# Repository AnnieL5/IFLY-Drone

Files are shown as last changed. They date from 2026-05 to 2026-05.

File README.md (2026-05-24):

## IFly, our Quadcopter Drone
Introducing IFly, our UAV (unmanned aerial vehicle) RC (remote control) quadcopter drone that can be controlled via a Logitech game controller. Along with basic flying capabilities, it consists of an ESP-32 camera that provides live video feed of the drone, which can be viewed on the user’s computer/phone. 

The drone can be used for personal enjoyment, exploration purposes or experimental projects. 

Our target audience is anyone interested in using a drone: drone enthusiasts, researchers who need an aerial device, elderly people who have limited movement, law enforcement who need to monitor dangerous areas, and delivery services. 

## How to use it?

#### mechanics
3D Cad files

#### docs
- BOM
- Journal
- Other documents

#### Firmware

DRONECODE - Code stored on the drone (in the Raspberry PI Pico)

OFFICIAL_ComputerArduino - Code in the Arduino UNO for receiving controller input and rf communication

OFFICIAL_XBox - Code ran on a computer with any python interpreter. Receives Xbox input and sends it to the Arduino via Serial communication

OFFICIAL_CameraWebServer - code for the ESP32-CAM module

## User Guide

### Safety: 
- Always fly in open space, away from people, wires, trees, and airports;
- Check for no fly zones in your region;
Do not fly in poor weather conditions such as raining, windy, or thunderstorms 
- Keep the drone within line of sight;
- Do not touch the propellers during operation/when spinning;
- Wear safety glasses for extra protection.

### Before Flight:
- Make sure the battery is sufficiently charged (between 14.8V to 16.8V);
- Place the drone on a flat ground, in an open space away from people;
- For safety reasons, tie the legs of the drone to some heavy objects to prevent accidents;
- Double check that the propellers are tight and there are no loose screws.

### Attaching the Battery:
- Carefully slide the battery into the space under the blue block/upper frame plate with the power cords facing the back of the drone (white arms);
- Strap the battery onto the drone with the provided velcro;
- Adjust the position of the battery so it aligns with the white line;
- Plug in the balance port to the battery checker, with the negative side plugged on the left side of the checker.

### Taking a Flight - Change Throttle:
- If the product is not pre-uploaded with the change throttle code;
- Download files in DRONECODE from https://github.com/AnnieL5/TEJ4M-Drone2024-25/tree/master 
- Open Thonny and connect to the Raspberry Pi Pico via a Micro-USB cable;
- Upload all downloaded files to Pico;
- Save the files;
- Open Arduino IDE on another computer, plug in the Arduino-RF Transmitter and open Serial Monitor;
  
    The following message should appear: 
    “Arduino TX Starting
    TX Ready…
    Please enter the message you wish to be communicated:”

- Plug in the battery to power the drone;
- The drone should beep 6 times; the gyro will then calibrate and the propellers will start rotating within 10 seconds;
- Send a number with two decimal places via the Serial Monitor to change the speed of the propellers (currently at 1.10, take-off at 1.35, landing at 1.00 and max 2.00).The motors will emergency stop once the drone has tilted more than 15 degrees in pitch or roll; power cycle to restart. 

### Taking a Flight - Controller Input:
- If the product is not pre-uploaded with the Controller Input code,

    Download files in DRONECODE from https://github.com/AnnieL5/TEJ4M-Drone2024-25/tree/ChangThrottle ;
    Open Thonny and connect to the Raspberry Pi Pico via a Micro-USB cable;
    Upload all downloaded files to Pico;
    Save the files.

- Open Arduino IDE on another computer, plug in the Arduino-RF Transmitter and the controller:

    The following message should appear: 
    “Arduino TX Starting
    TX Ready…
    Please enter the message you wish to be communicated:”
- Plug in the battery to power the drone
- The drone should beep 6 times and the gyro will calibrate;
- Press the specific button on the diagram to start the drone; it will take-off automatically
- Follow the diagram to control the drone. It will emergency stop once the drone has tilted more than 15 degrees in pitch or roll; power cycle to restart. There is also a safety time limit of 60 seconds once the drone takes off (throttle above 1.1).

### Camera - Acess the code in the CameraWebServer branch
**First time use:**

    Open Arduino IDE;
    Plug in the camera to the computer using a USB-MicroUSB cable;
    Download and open the files in the OFFICIAL_CameraWebServer from Github;
    Change the WIFI credentials to your own WIFI name and password;
    Upload the code;
    Open Serial Monitor and wait for it to provide a link to a website;
    Open the link in any browser.

**Other times:**
- Power the camera using 5V and connect to GND;
- Open WIFI/Hostpost that is recorded in the program stored inside the module;
- Wait until the camera is connected;
- Open the same website as the first time use and enjoy.

### Battery Maintenance:
- Do not puncture, wet, or throw the battery;
- Replace the battery if it puffs, has unusual smell, or smokes;
- Do not go below 3.7V per cell (can be seen from the battery checker);
- Always use a quality Lipo battery charger when charging or discharging;

**Charging**
- Never leave the battery charging unattended;
- Always balance charge the battery at a 1C rate (3.3A) to a max of 16.8V (or 4.2V per cell);
- Do not overcharge the battery.

**Discharging**
- Never discharge the battery unattended;
- Discharge battery back to storage level (3.85V per cell) if you are not going to use the drone again for a long period of time (3 days or more);
- Discharge at a rate of 1C or less (or whatever rate the charger deems appropriate);
- Never completely discharge the battery, unless it is to be disposed;
- Store the battery on a non-flammable surface and away from flammable objects; do not keep the battery plugged in if you are not using the drone.

## Thanks for checking it out!
Made by Jennifer Liu and Tianyi(Annie) Liang. 

If there are any questions or if you would like to contribute, please reach out to atianyi.liang@gmail.com. Your support is greatly appreciated!

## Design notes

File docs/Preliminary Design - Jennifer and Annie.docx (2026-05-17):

Preliminary Design Document

for “Drone”

Version 1.0

Jennifer and Annie

Oct 27, 2024

# Table of Contents

Table of Contents 2

1. Introduction 3

1.1 Project Overview 3

2. Product Design 4

2.1 Block Diagram 4

2.2 Sub-Circuit Descriptions 4

2.2.1 Sub-Circuit #1: ESCs (Electronic Speed Controllers) 4

2.2.2 Sub-Circuit #2: ESCs, Motors, and Propellers 5

Battery 6

2.2.3 Sub-Circuit #3: Raspberry Pi Pico and Active Buzzer 6

2.2.4 Sub-Circuit #4: Raspberry Pi Pico and MPU-6050 7

2.2.5 Sub-Circuit #5: RF transceivers 7

2.2.6 Sub-Circuit #6: Raspberry Pi Pico, RF transceiver, and SPI 8

SPI Communication 9

2.2.7 Sub-Circuit #7: Arduino Leonardo and RF Transceiver 9

2.2.8 Sub-Circuit #8: ESP32 CAM-MB 10

2.3. Product Interfaces 10

2.3.1 Internal Interfaces 10

2.3.1.1 Raspberry Pi Pico and ESCs 10

2.3.1.2 ESCs and Motors 11

2.3.1.3 4s Lipo Battery and ESCs 11

2.3.1.4 4s Lipo Battery and Power Switch 12

2.3.1.5 Raspberry Pi Pico and MPU-6050 12

2.3.1.6 Raspberry Pi Pico and NRF24L01 Transceiver 12

2.3.1.7 Raspberry Pi Pico and ESP 32-CAM-MB 12

2.3.2 External Interfaces 13

2.3.2.1 Arduino Leonardo and NRF24L01 Transceiver 13

2.3.2.2 Xbox Controller and Arduino Leonardo 13

2.3.2.3 Communication between NRF24L01 Transceivers 13

2.3.2.4 ESP 32-CAM and Computer 13

2.3.2.5 Battery pack and Arduino Leonardo 14

3. Scheduling 14

3.1 Tasks 14

Task #1: Drone 14

Task #2: Camera 14

3.2 Gantt Chart Schedule 15

APPENDIX 16

Appendix A. Schematic 16

Appendix B. Parts List 16

Appendix C. References 19

# 1. Introduction

## 1.1 Project Overview

The Drone - as indicated by its name - is an UAV (unmanned aerial vehicle) VTOL (vertical Take-Off and landing) quadcopter drone, perfect for anyone interested in aerospace or aviation, enthusiasts looking for a fun new hobby, or researchers who might need an aerial device for experiments! The drone can be controlled through an XBox controller and is equipped with a camera, where live video data can be accessed from any computer. The drone also has a self-powered buzzer, great for easy identification of the drone amidst crashes or accidents. The drone flies in acro mode, intended for stable and non-rigours flying (i.e not for racing). Our made-up client is a Canadian drone manufacturer that wants us to design and build a prototype for a new quadcopter drone model. The end users will be the customers who are looking to purchase a drone. However, the drone is actually a project for the Grade 12 Computer Engineering course, TEJ4M, where the goal is to learn more about various engineering concepts while covering off the majority of the curriculum’s expectations. For a summary of the requirements of this project, please see the Hardware Requirements Specification (HRS) document for the Drone.

# 2. Product Design

## 2.1 Block Diagram

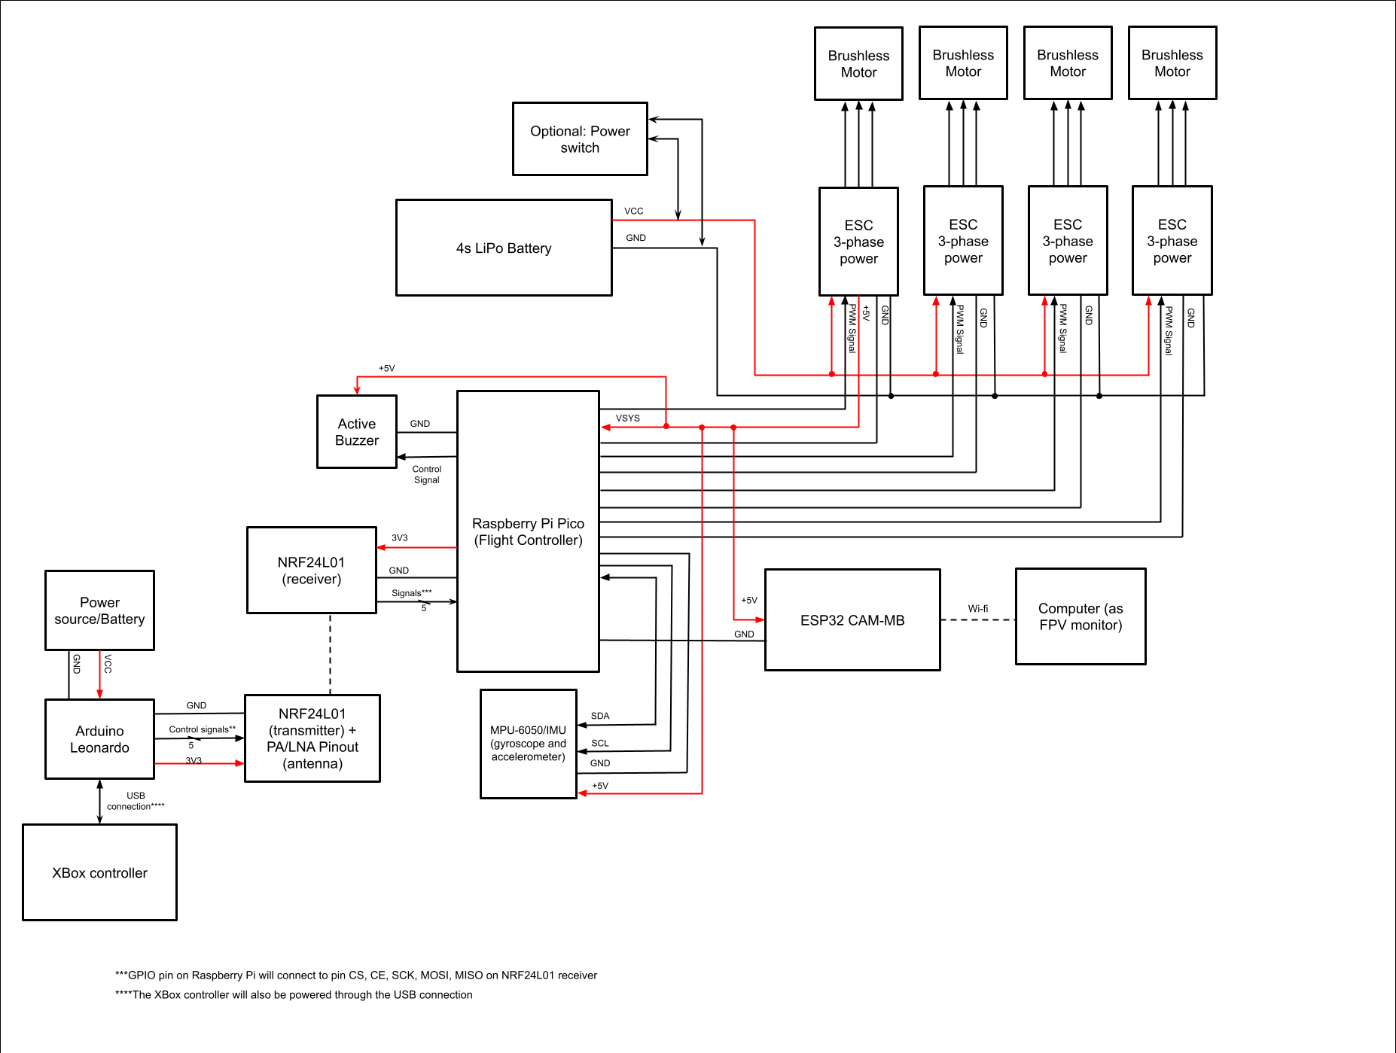
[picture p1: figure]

## 2.2 Sub-Circuit Descriptions

### 2.2.1 Sub-Circuit #1: ESCs (Electronic Speed Controllers)

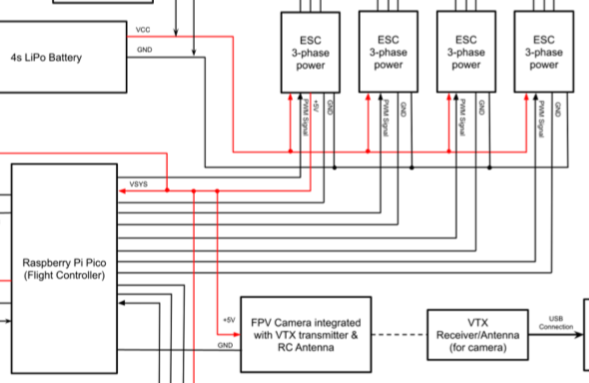
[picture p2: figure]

4 brushless ESCs will be used to control the throttle of each motor. The Raspberry Pi Pico has limited current (maximum output current of 12mA) and voltage output on its GPIO pin. In addition, it cannot generate the precise three-phase control needed to drive the motors. Therefore, an ESC will be used to control the speed of each motor.

The flight controller (Raspberry Pi Pico) uses PID controllers to determine the necessary adjustments to the speed of each motor to achieve the desired orientation (pitch, roll, yaw) of the drone. This process involves calculating the error between the desired angular rates (from the pilot's input via the Xbox controller) and the actual angular rates measured by the MPU-6050 for each axis. The PID controller computes correction values using proportional, integral, and derivative terms, each scaled by their respective gain values. The sum of these terms provides the control signal for each axis, which is then used to adjust the speeds of individual motors accordingly. Throttle (overall thrust) is managed separately to control altitude, with the PID adjustments superimposed to maintain or change orientation.

The flight controller, utilizing a Raspberry Pi Pico, communicates with each Electronic Speed Controller (ESC) through Pulse Width Modulation (PWM) signals. The duty cycle of the PWM signal dictates the throttle level: a higher duty cycle results in faster motor rotation. Specifically, the PWM signal operates at a frequency of 50 Hz, where a pulse width of 1 ms corresponds to zero throttle and a pulse width of 2 ms signifies full throttle. Throttle adjustments are made incrementally between these two pulse widths.

Each ESC contains a microcontroller connected to six MOSFET transistors—two MOSFETs per motor wire. These MOSFETs function as switches, regulating the current to the motor's three-phase coils. At higher throttle levels, the MOSFETs switch more rapidly, increasing the motor's speed. Between the ESC microcontroller and the MOSFETs lies a gate driver, which amplifies the low-voltage PWM signals from the microcontroller to the high-voltage required by the MOSFETs.

The PWM signals for each ESC (U4-3, U5-3, U6-3, U7-3) are connected to corresponding GPIO pins on the Raspberry Pi Pico (U1-4, U1-34, U1-20, U1-21).

Each ESCs is powered through the 4S Lipo battery and connected to both the battery’s ground and GND pins (U1-3, U1-18, U1-33, U1-23) on the Raspberry Pi Pico. The power and ground wires for the ESC will be soldered directly to the PCB board of the frame.

Unlike a linear BEC, a switching BEC uses a small FET transistor to rapidly switch the battery voltage on and off. This switched voltage is then filtered through an inductor and capacitor to smooth out the ripple, producing a steady DC voltage. This method avoids overheating and reduces power wastage.To avoid buying another separate on-board voltage regulator, the Raspberry Pi Pico will be powered through the VSYS pin (U1-39) by one of the ESCs (U4-4).

### 2.2.2 Sub-Circuit #2: ESCs, Motors, and Propellers

4 SunnySky 2212 980kv brushless motors will be used, each with a 9450 2-blade propeller.

Compared to brushed motors, brushless motors have minimal friction and are more efficient. 2212 motors are a common and popular motor size for the F450 frame, measuring 22mm in stator diameter and 12mm in stator height - these dimensions allow for a balance in motor responsiveness and cooling.

Loaded with all the parts, the drone weighs a total of ~1155g. To achieve a thrust-to-weight ratio of at least 2:1, each motor needs to be able to produce at least 578g of thrust. With a larger frame such as the F450, larger propellers are more suitable as they can move more air and thus generate more thrust. They also provide better flight stability. To generate the greater amount of torque needed to achieve the thrust required for the larger propellers, a lower motor Kv rating is required. This is due to the inverse relationship between torque constant (amount of torque produced per amp of current to the motor) and Kv: K_t (Torque constant) = 1/(K_v) . Since T(torque)=K_t * Current , a higher torque constant generates more torque, which in turns generates more thrust. Accordingly, based on the thrust table below for the 2212 980v motor, the motor can produce over 578g of thrust with a 4S lipo (14.8V) and 9450 propellers while maintaining fair efficiency.

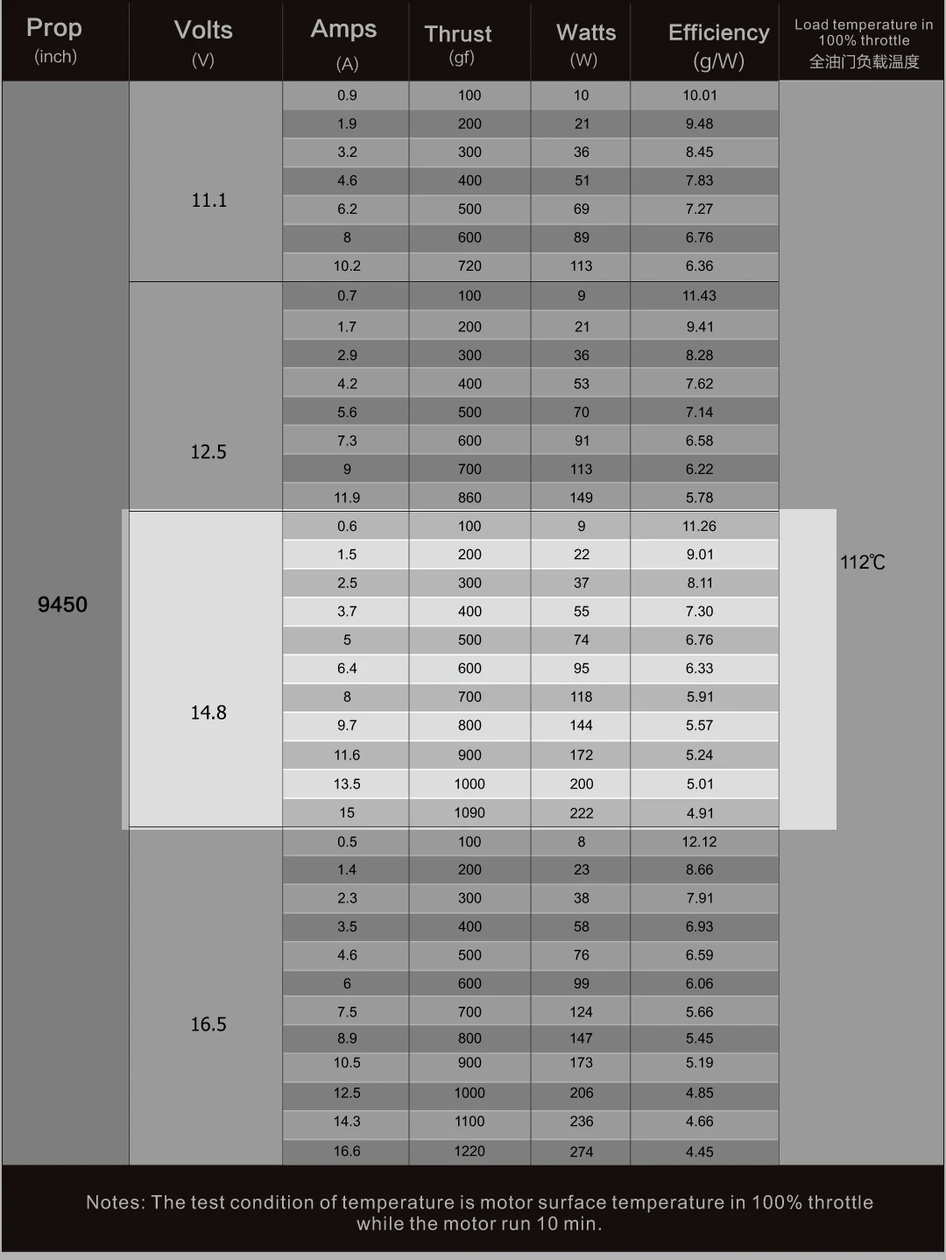
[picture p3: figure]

Each motor will be powered through three phase power from the ESCs. The motor is rated to have maximum continuous current of 20A/30S. Our ESCs are rated for a continuous current output of 30A, well above a 20% increase of the motor’s max current draw, ensuring that the ESCs won’t overheat.

Calculations from ecalc (https://ecalc.ch/xcoptercalc.php) based on components configurations for the drone:

*The results show that the electric power required is over the maximum power rating for the motor. However, this is most likely due to incorrect data from ecalc. Ecalc rates the maximum power limit for SunnySky 2212 980kv motors to be 115W, while SunnySky states that the motor has a maximum continuous power of 330W. Therefore, the motor should be able to generate enough power, and ecalc results are incorrect.

### Battery

The drone will be powered by a 4S 3300mAh Lipo Battery, with a minimum discharge rate of 60C and a nominal voltage of 14.8V. This provides ample current and voltage to the ESCs and motors.

Max Current = Battery Capacity & C rating

Max Current = 3.3 Ah * 60

Max Current = 198A

Each motor has a maximum current draw of 20A: Max current draw = 20*4 = 80A

Therefore the battery can safely handle the motor’s current draw. Each ESC is rated for a voltage input of 6.4v - 16.8v.

### 2.2.3 Sub-Circuit #3: Raspberry Pi Pico and Active Buzzer

The active buzzer with built-in 80mAh Lipo battery will be used for easy identification of the drone amidst crashes or accidents.

If the battery disconnects, the buzzer will sound in low volume for 40 seconds. After 40 seconds, the buzzer will sound at max volume of up to 110db for 40 seconds. The buzzer will flash a blue light in low light settings.

To manually activate the buzzer (if the battery isn’t disconnected):

The buzzer activates when current flows from BUZ+ to BUZ-. The buzzer has 3 connections with the Raspberry Pi Pico: BUZ+, GND, and BUZ-. BUZ+ (BZ1-1) is connected to VSYS (U1-39) on the Raspberry Pi Pico. GND (BZ1-3) is connected to GND (U1-28) on the Pico. BUZ- acts as the negative terminal for the buzzer’s internal circuits. When BUZ- is connected to GND, the circuit is complete and current flows through the buzzer, thereby activating it. Due to the limited current that GPIO pins can handle, a 2N7000 MOSFET will be used as a switch between BUZ- & GND. The transistor will be connected to a GPIO 22 (U1-29) on the Pico through a 1 kΩ resistor (to protect the pin from current spikes during switching).

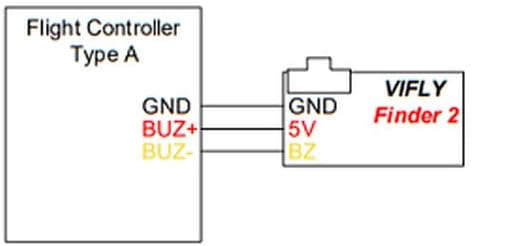
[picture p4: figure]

BUZ- will be connected to the drain of the transistor, and the source will be connected to a GND (U1-28) on the Pico. Since the transistor is used as a switch, it will operate only between the cutoff and saturation regions, not the linear (active) region.

GPIO 22 (U1-29) controls the gate voltage, which controls the drain-source channel, but is electrically isolated from the high-current path of the buzzer; the gate draws an extremely small current, protecting the GPIO pin from excessive load. The transistor has a continuous drain current of 200mA, which should be sufficient to handle the buzzer’s current.

When GPIO 22 is set HIGH (3.3V), the N-MOSFET turns on, the gate-source voltage (V_GS) exceeds the threshold voltage required to turn on the MOSFET. The MOSFET enters the enhancement mode and conducts between drain and source. This connects BUZ- to GND, and the buzzer activates.

### 2.2.4 Sub-Circuit #4: Raspberry Pi Pico and MPU-6050

A MPU-6050 will be used to measure the actual orientation along the three axes (pitch, roll, and yaw) at any time by measuring the drone’s angular velocity and linear acceleration. The MPU-6050 is a six-axis Inertial Measurement Unit (IMU) that combines a three-axis gyroscope and a three-axis accelerometer.

The MPU-6050 communicates with the Raspberry Pi Pico through I2C serial communication protocol. In this case, the Raspberry Pico is the master and the MPU-6050 is the slave. As the MPU-6050 is the only slave on the bus, AD0 will connect to GND (U1-13) on the Pico, setting the I2C address to the default 0x68. To attain specific data or initialize the MPU-6050 for communication, the Pico will write to specific register addresses: 0x6B for power management, 0x3B to 0x40 for accelerometer data and 0x43 to 0x48 for gyroscope data. To read sensor data, the Pico will first send the slave address of the MPU-6050 with a write flag over the SDA line. It will then transmit the specific register address from which it wishes to retrieve data. After setting the register address, the Pico switches to a read flag to initiate data retrieval. An ACK/NACK bit is sent between each command to verify that the request has been received. Data frames are then sent over to the Pico, where a NACK bit from the Pico will stop the reading.

The MPU6050 has an internal built-in low dropout regulator, allowing VDD to directly connect to VSYS on the Raspberry Pi. Since the Raspberry Pico has built-in pull-up resistors for its I2C compatible pins, no external pull-ups are necessary when connecting the SDA and SCL lines. GND on the MPU-6050 is connected to a GND pin on the Raspberry Pi.

### 2.2.5 Sub-Circuit #5: RF transceivers

Communication between the two RF transceivers is for transmitting the pilot's input for drone movement. It sends the signals from the XBox controller to the drone.

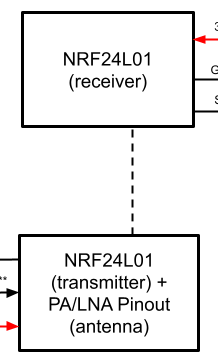
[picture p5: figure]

The drone uses two NRF24L01 modules for communication, which is a single chip transceiver that operates on the 2.4GHz ISM frequency brand. Due to its half-duplex design, each module can only send (TX mode) or receive (RX mode) data bus, not both. This module is chosen for its low energy consumption and excellent operational range of up to 1000m.

The nRF24L01 uses a specific frequency, known as a channel, to transmit and receive data. The frequency ranges between 2400 and 2525 MHz, which provides it with 125 (1MHz each) independent RF channels for one module to communicate with other parts. The two RF transceivers must be on the same channel to communicate with each other and the RF channel frequency can be calculated using the following formula:

Freq(Selected) = 2400 + CH(Selected)

Therefore if the communication channel between the two RF transceivers we used is 18, then the selected frequency would be 2418MHz.

The nRF24L01 uses the Enhanced ShockBurst packet structure.

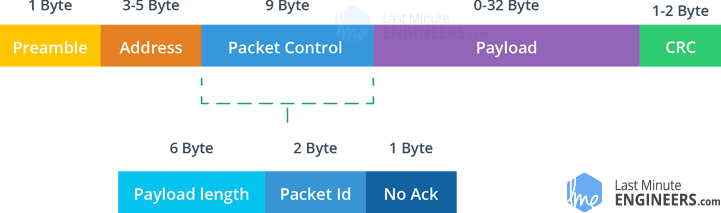
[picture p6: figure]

This allows the payload length to range from 1-32 bytes and each packet is assigned a packet ID that allows the receiver to check if the packet is new or has been received.

Each message contains a field asking for the Acknowledgement (ACK). The receiver sends it once the message has been successfully received, eliminating any potential loss of controlling command lost during communication.

### 2.2.6 Sub-Circuit #6: Raspberry Pi Pico, RF transceiver, and SPI

The RF transceiver on the drone is a wireless communication module that acts as a RF receiver on the drone for receiving the pilot’s input. It has an on-board antenna and obtains signals such as pitch, roll, yaw, and throttle from the other RF transceiver module on the controller and sends it to the flight controller for processing powering of the motors.

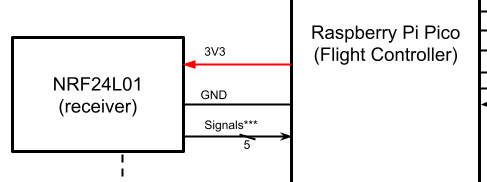
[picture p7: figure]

The RF transceiver operates at ~12mA during transmission and requires a voltage of 1.9-3.6V. Due to its low power consumption, it can be easily powered using any GPIO pin (U1-7) on the Pico. The transceiver’s GND is connected to GND (U1-8) on the Pico. The RF transceiver outputs signals from pin CE, CS, SCK, and MOSI to GPIO10 (U1-14), GIPO9 (U1-12), GIPO6 (U1-9), GIPO7 (U1-10), in corresponding order.

#### SPI Communication

SPI, Serial Peripheral Interface, is an interface bus commonly used for synchronous serial communication. It uses separate clock and data lines to send data between a controller and small peripherals.

NRF24L01 communicates via SPI, which makes it compatible with many microcontrollers. It has some changeable registers that need to be configured using 250 kbps, 1 Mbps or 2 Mbps. Some examples of registers include frequency channel and air data rate. Pin MOSI, SCK, and MISO on the RF transceiver are for SPI communication.

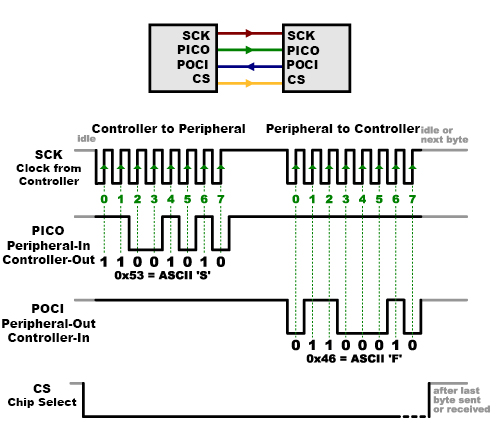
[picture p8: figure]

The diagram shows a visual representation of different lines and how it functions.

SCK is used for clock signals that oscillate to indicate the receiver exactly when to analyze the bits on the data line. It can be rising or falling edge detection.

MISO, which also stands for POCI, is for data transmission from the flight controller (Raspberry Pi Pico) to the peripheral (NRF24L01). On the drone it will not be used as we only need to send signals from the Arduino to the Pico.

On the other hand MOSI (PICO) is used for sending data from the NRF24L01 to the Raspberry Pi. When the receiver detects the edge of the clock, it will immediately look at the data to read the next bit.

The CE pin used to control data transmission and enabling RX or TX mode.The CSN pin on the RF transceiver is connected to the Raspberry Pi for chip select line. It tells the peripheral when to receive or send the data and is usually held high, which disconnects the two.

### 2.2.7 Sub-Circuit #7: Arduino Leonardo and RF Transceiver

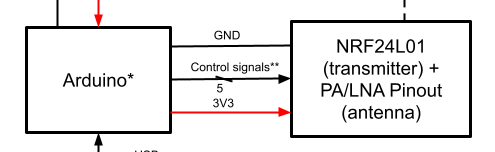
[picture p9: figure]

The RF transceiver on the controller sends signals of the joystick and buttons to the RF transceiver on the drone. In addition to the NRF24L01 chip, it consists of a duck antenna, PA (Power Amplifier), and LNA(Low-Noise Amplifier), which raise the signal's transmission distance to up to 1000 meters in open space.

Compared to the above subcircuit 2.2.6, it communicates with an Arduino Leonardo instead of a Raspberry Pi. Due to its numerous libraries, an Arduino is easier to work with, such as premade ones for SPI communication and communicating with NRF24L01.

To power the RF transceiver, we connect the VCC (U10-2) pin to 5V (U9-33) on the Arduino Leonardo and GND (U10-1) to GND (U9-34).

Pin CE (U10-3), CSN (U10-4), SCK (U10-5), MOSI (U10-6), MISO (U10-7) connect to the corresponding pins D9 (U9-24), D10 (U9-25), SCLK (U9-9), MOSI (U9-11), MISO (U9-10) on the Arduino.

The RF transceiver communicates to the Arduino via Serial Peripheral Interface (SPI), which is explained in the section 2.2.6.

### 2.2.8 Sub-Circuit #8: ESP32 CAM-MB

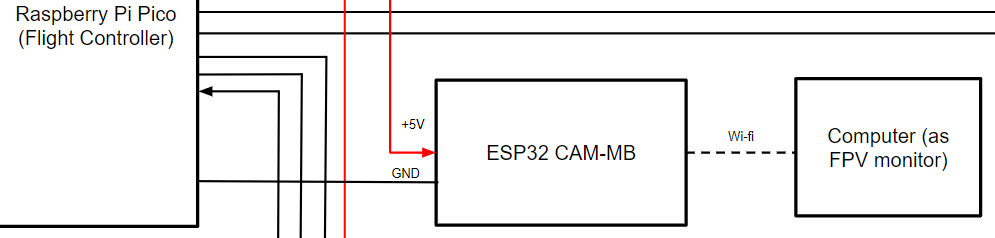
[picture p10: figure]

ESP32-CAM-MB provides the camera function for the drone. With a ESP32-S chip and a OV2640 camera sensor, it is able to record video and stream it to the computer. If required, it is also capable of performing image processing because of its 32-bit core microprocessor.

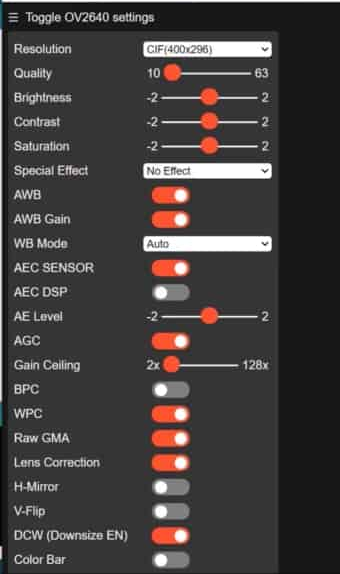
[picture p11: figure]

The ESP32-CAM streams the video to a computer via Wifi. It has an on-board PCB trace antenna as well as a u.FL connector for potential connection to external antennas. Since the PCB antenna has a gain of 2.1dBi, which means it can transmit signals to a max of 100m, we would need an external antenna to enhance the range.

The ESP32-CAM is enough for camera purposes, while an additional board with a usb port is added (ESP-32-CAM-MB) to make programming easier. It is only needed to connect the usb port to a computer and the chip could be programmed using Arduino IDE with an existing library. Once the wifi is configured, a live website link would be generated and the image could be viewed there. The left side is an image of the website interface and any additional features that can be modified.

The 3.3V pin (U8-9) on ESP32-CAM-MB connects to the 3V3 pin (U1-36) on the Pico. GND (U8-2) connects to GND (U1-42) on the Pico.

## 2.3. Product Interfaces

### 2.3.1 Internal Interfaces

#### 2.3.1.1 Raspberry Pi Pico and ESCs

From | To | Signal Name
U1-4 (GPIO2) | U4-3 | PWM_1
U1-34(GPIO28) | U5-3 | PWM_2
U1-20 (GPIO15) | U6-3 | PWM_3
U1-21 (GPIO16) | U7-3 | PWM_4
U4-4 | U1-39 (VSYS) | VSYS
U1-3 | U4-5 | GND
U1-33 | U5-5 | GND
U1-18 | U6-5 | GND
U1-23 | U7-5 | GND

#### 2.3.1.2 ESCs and Motors

From | To | Signal Name | Description
U4-6 (U) | M1-1 (U) | Phase U1 | Standard connection for CW rotation
U4-7 (V) | M1-2 (V) | Phase V1 | Standard connection for CW rotation
U4-8 (W) | M1-3 (W) | Phase W1 | Standard connection for CW rotation
U5-6 (U) | M2-1 (V) | Phase U2 | Swapped connection for CCW rotation
U5-7 (V) | M2-2 (U) | Phase V2 | Swapped connection for CCW rotation
U5-8 (W) | M2-3 (W) | Phase W2 | Standard connection
U6-6 (U) | M3-1 (V) | Phase U3 | Swapped connection for CCW rotation
U6-7 (V) | M3-2 (U) | Phase V3 | Swapped connection for CCW rotation
U6-8 (W) | M3-3 (W) | Phase W3 | Standard connection
U8-6 (U) | M4-1 (U) | Phase U4 | Standard connection for CW rotation
U8-7 (V) | M4-2 (V) | Phase V4 | Standard connection for CW rotation
U8-8 (W) | M4-3 (W) | Phase W4 | Standard connection for CW rotation

#### 2.3.1.3 4s Lipo Battery and ESCs

From | To | Signal Name | Description
SW1-1 | U4-1 | +BATT | Voltage source
SW1-1 | U5-1 | +BATT | Voltage source
SW1-1 | U6-1 | +BATT | Voltage source
SW1-1 | U7-1 | +BATT | Voltage source
BT1-GND | U4-2 | GND | --
BT1-GND | U5-2 | GND | --
BT1-GND | U6-2 | GND | --
BT1-GND | U7-2 | GND | --

#### 2.3.1.4 4s Lipo Battery and Power Switch

From | To | Signal Name | Description
SW1-2 | SW1-3 | OFF | Power switch is off, no power flow
SW1-2 | SW1-1 | ON | Power switch is on, there is power flow

#### 2.3.1.5 Raspberry Pi Pico and MPU-6050

From | To | Signal Name
U1-39 (VSYS) | U3-13 (VDD) | VDD
U1-13 | U3-18 | GND
U3-9 | U1-13 | ADO
U3-24 | U1-16 | SDA*
U1-17 | U3-23 | SCL

*Bidirectional

#### 2.3.1.6 Raspberry Pi Pico and NRF24L01 Transceiver

From | To | Signal Name
U1-7 | U2-2 | VCC
U1-8 | U2-1 | GND
U2-3 | U1-13 | CE
U2-4 | U1-12 | CS
U2-5 | U1-9 | SCK
U2-6 | U1-10 | MOSI

#### 2.3.1.7 Raspberry Pi Pico and ESP 32-CAM-MB

From | To | Signal Name
U1-36 | U8-9 | 3V3
U1-42 | U8-2 | GND

### 2.3.2 External Interfaces

#### 2.3.2.1 Arduino Leonardo and NRF24L01 Transceiver

From | To | Signal Name
U9-33 | U10-2 | VCC
U9-34 | U10-1 | GND
U9-9 | U10-5 | SCK
U9-11 | U10-7 | MISO
U9-10 | U10-6 | MOSI
U9-24 | U10-3 | CE
U9-25 | U10-4 | CSN

#### 2.3.2.2 Xbox Controller and Arduino Leonardo

From | To | Signal Name
U11-1 | U10-35 | USB Connection

#### 2.3.2.3 Communication between NRF24L01 Transceivers

From | To | Signal Name | Description
U10 | U2 | RF Transmission | To transmit pilot input from XBox controller to Raspberry Pi Pico

*See subcircuit 2.2.5 for more information

#### 2.3.2.4 ESP 32-CAM and Computer

From | To | Signal Name
U8 | Computer | Wi-Fi*

*There are multiple modes in which ESP 32-CAM can connect to Wifi:

1. Station Mode (STA): Connects to an existing Wi-Fi network (like a router)
2. Access Point Mode (AP): Creates its own Wi-Fi network for devices to connect directly
3. Dual Mode (STA + AP): Operates in both modes simultaneously

#### 2.3.2.5 Battery pack and Arduino Leonardo

From | To | Signal Name
BT2 | U9-8 | +12V

# 3. Scheduling

## 3.1 Tasks

#### Task #1: Drone

(30% ~23 days)

1. Order parts
2. Calibrate Raspberry Pi Pico (i.e load code) (3 days)
3. Create simple programs to test out different parts (2 weeks)
  a. Battery
  b. Raspberry Pi Pico + ESCs + Motors
    i. Power Raspberry Pi Pico through ESCs
  c. Calibrate + Test MPU-6050
  d. Calibrate + Test Arduino Leonardo & XBox controller
    i. Receive data from XBox
    ii. RF transmission between the RF transceivers
  e. Test buzzer
4. Assemble parts to frame (1 week)
  a. Solder ESCs & battery to PCB board
  b. Assemble frame + attach motors and propellers
  c. Solder ESC signal connectors to Raspberry Pi
  d. 3d Raspberry Pi platform (optional/if needed)
  e. Attach all other components

(60% - 47 days)

5. Code RF transceiver + Controller
6. Code motors + MPU-6050
  a. Test without propellers
  b. Connect MPU-6050
  c. PID tuning
7. Code other components
  a. Buzzer
  b. Power switch (optional)
8. Final Testing

#### Task #2: Camera

(10% ~ 4 days)

1. Set up + code camera
  a. Get IP address
  b. Access the live website
2. Assemble it to the drone
3. (If have time: Add speed detection/AI program to it)

*Bolden tasks are inputted in the Gantt Chart, unboldened tasks are considered subsections in of the bolded task in the Gantt Chart

## 3.2 Gantt Chart Schedule

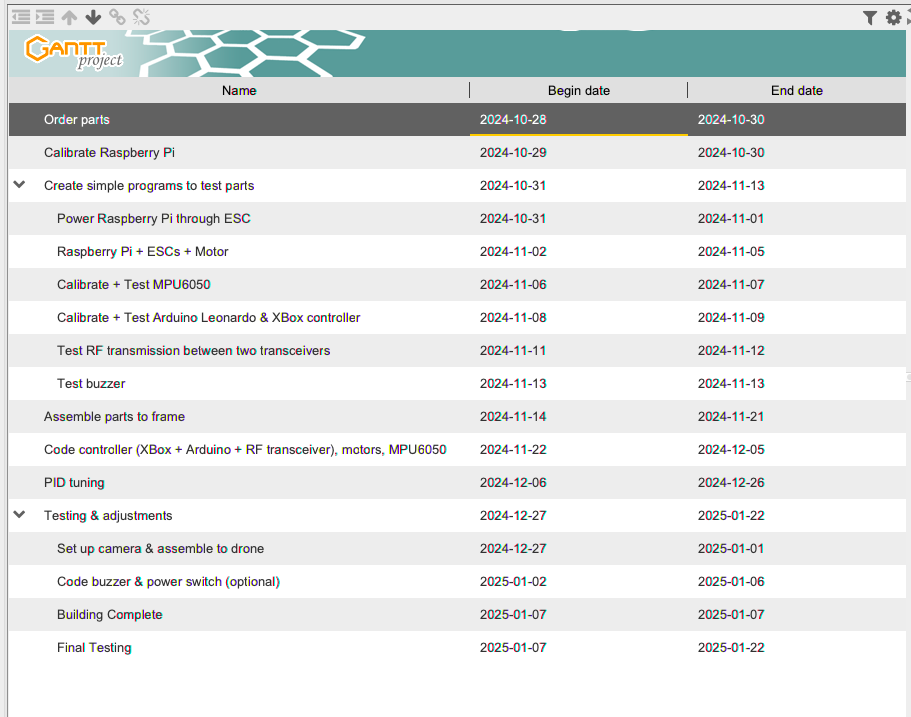
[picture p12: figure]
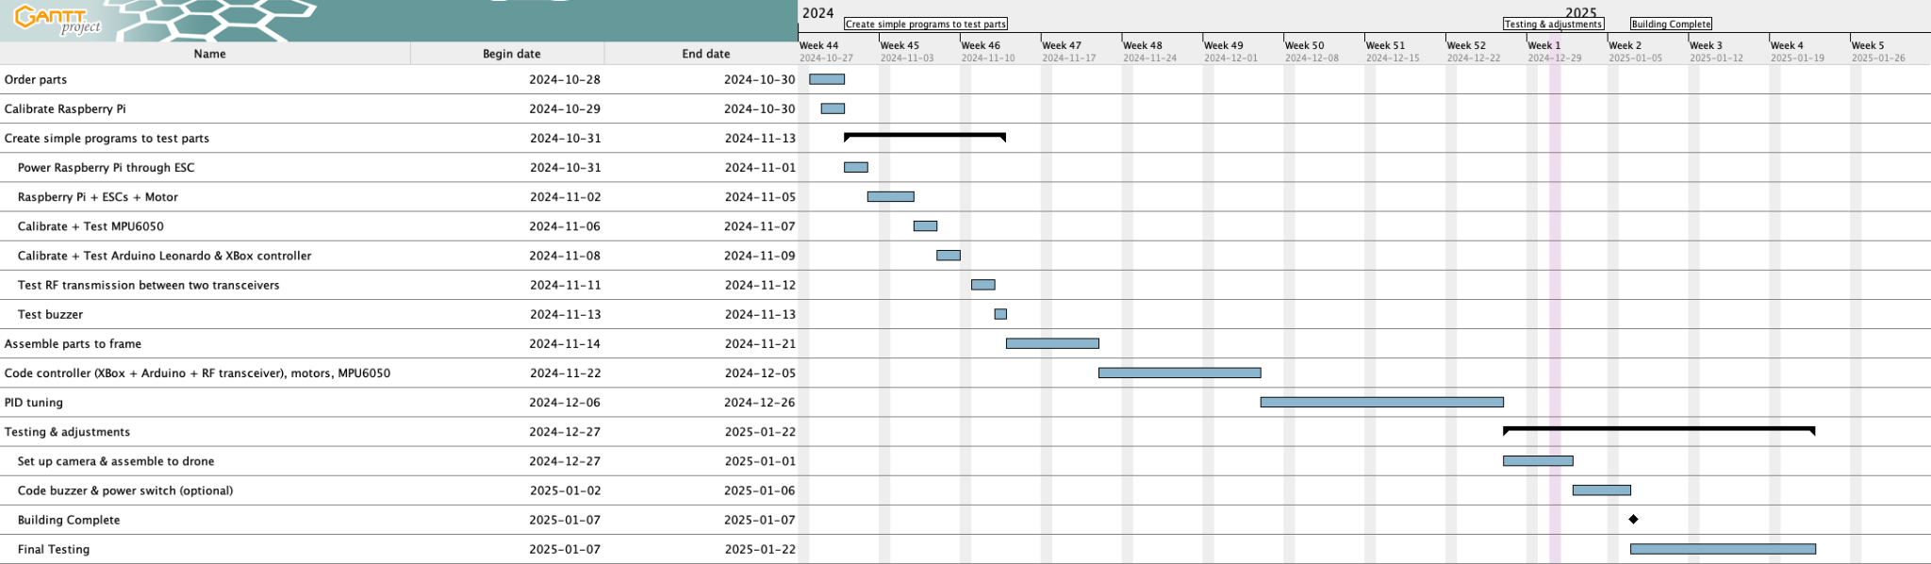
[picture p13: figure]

*Also uploaded in assignment submission

# APPENDIX

## Appendix A. Schematic

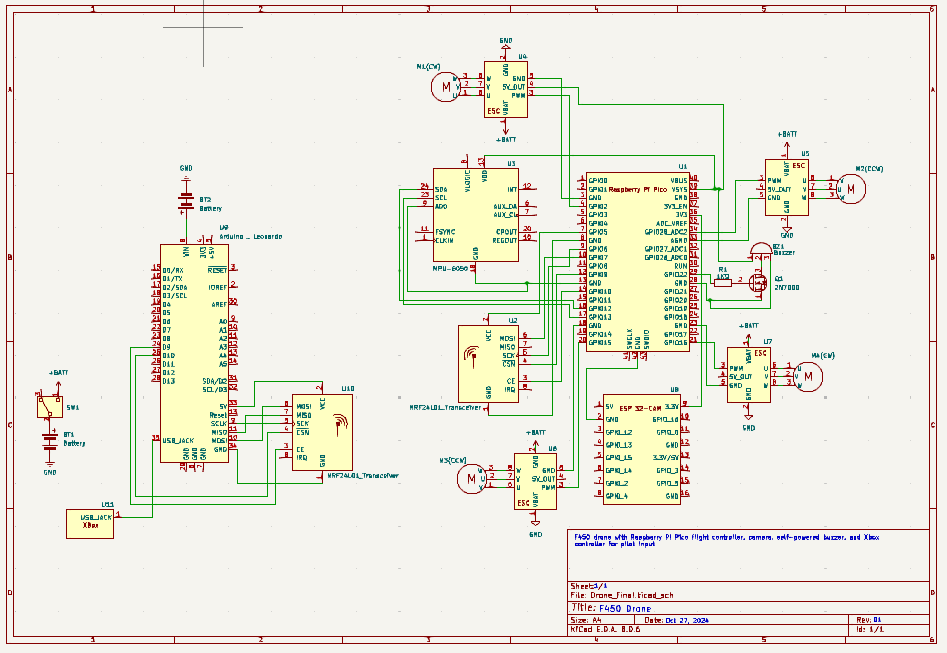
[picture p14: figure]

*Not the best image quality, a better quality pdf version is attached to the assignment submission

## Appendix B. Parts List

Part Name | Reference Designator | Quantity | Link | Notes
Raspberry Pi Pico | U1 | 1 | https (https://www.pishop.ca/product/raspberry-pi-pico-non-wireless/?src=raspberrypi)://www.pishop.ca/product/raspberry-pi-pico-non-wireless/?src=raspberrypi | +2$ local pick up fee
MPU6050 | U3 | 1 | Gikfun GY-521 MPU-6050 3 Axis Accelerometer Gyroscope Module 6 DOF 6-axis Accelerometer Gyroscope Sensor Module for Arduino DIY(Pack of 3) EK1091x3C (https://www.amazon.ca/sspa/click) | Pack of 3
ESCs | U4, U5, U6, U7 | 4 | https://www.amazon.com/RC-Brushless-Electric-Controller-bullet/dp/B071GRSFBD?th=1
F450 Frame | N/A | 1 | https://www.amazon.ca/HAWKS-WORK-Quadcopter-Original-version/dp/B09YQ4G4ZZ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
Buzzer | BZ1 | 1 | https://www.amazon.ca/VIFLY-Finder-Battery-Compatible-Standalone/dp/B07JB65HZC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
ESP 32-CAM-MB | U8 | 1 | https://www.amazon.ca/dp/B0CGRK4PZ9/ref=twister_B0DG61WS8R?_encoding=UTF8&th=1
NRF2401 transceivers | U2, U10 | 1 | https (https://www.amazon.ca/diymore-NRF24L01-Transceiver-Development-Compatible/dp/B0CGTWQ1BP)://www.amazon.ca/diymore-NRF24L01-Transceiver-Development-Compatible/dp/B0CGTWQ1BP/ref=sr_1_2?crid=N7UCP8G6BI4B&dib=eyJ2IjoiMSJ9.QZWyUbxu-TTSXPtYa6jWsruNzInPMMFV3gyAWClyr16MjHZf7YNdMQIuLN8GSAJLMNuq_XRXSs0m0G5N2sjBIhiwK3Z4KvY9esEi6FYL8DDdseyeCPcQ7UDiiZB5kaqveZb2Wb01HFBp9DZ7mam3NE9XG7xw6UoxfQr9Gs2KcmLq1bCmSb6KFCsLg2RbVpZ_.s2cC8epe2nNatPfmenG33v9DyfE5sOt-iBPax3x-Jwg&dib_tag=se&keywords=nrf2401%2Bpa%2Blna&qid=1729738278&sprefix=nrf2401%2Bpa%2Blna%2Caps%2C100&sr=8-2&th=1 | Pack of 3

4S 3300mAh Lipo Battery

BT1

2

https://www.amazon.ca/3300mAh-Battery-Helicopter-Airplane-Quadcopter/dp/B06XKQJZ8D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
Motors (Sunnysky 2212 980kv brushless motors) | M1, M2, M3, M4 | 4 | https://sunnyskyusa.com/products/sunnysky-a2212-motors-multirotor-version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
Arduino Leonardo | U9 | 1 | https://www.amazon.ca/Leonardo-Headers-Compatible-Revision-Atmega32u4/dp/B00R237VGO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
XBox 360 controller | U11 | 1 | | Already own

Battery Charger

1

https://www.amazon.ca/Hobby-Fans-Professional-Balance-Discharger/dp/B09XC91BWJ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

9450 Propellers

4

https://www.amazon.ca/propellers-Self-Locking-Propellers-Quadcopter-Phantom/dp/B0858XGN37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 (for quick shipping)

https://www.aliexpress.com/item/32844447546.html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 (slower shipping)

Ones purchased from Aliexpress will be used during testing stage (cheap and therefore easy to replace if broken)
Battery Pack for Arduino Leonardo | | 1 | | Already own

## Appendix C. References

Raspberry Pi Pico: https://datasheets.raspberrypi.com/pico/pico-datasheet.pdf

MPU60-50:https://invensense.tdk.com/wp-content/uploads/2015/02/MPU-6000-Datasheet1.pdf

October 27, 2024 Page of 18

Preliminary Design Document for “Drone”

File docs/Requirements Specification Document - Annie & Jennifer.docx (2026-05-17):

Hardware Requirements Specification for Drone

Annie & Jennifer

Version 1.0

Table of Contents

1. Executive Summary 3

1.1 Project Overview 3

1.2 Purpose and Scope of this Specification 3

2. Product Description 4

2.1 Product Context 4

2.2 User Characteristics 4

2.3 Assumptions/Risks 5

2.4 Constraints 5

2.5 Dependencies 5

3. Requirements 6

3.1 Functional and Hardware Requirements 6

3.1.1 General Functional Objectives 6

3.1.2 Propellers 7

3.1.4 Flight Controller (FC) 8

3.1.5 Camera 9

3.2 User Interface Requirements 9

3.3 Hardware Interfaces 10

3.3.1 Internal Interfaces (drone) 10

3.3.2 External Interfaces (Controller, FPV monitor) 11

4. Requirements Confirmation/Stakeholder sign-off 12

APPENDIX 12

Appendix A. Definitions, Acronyms, and Abbreviations 12

Appendix B. References 12

## 1. Executive Summary

### 1.1 Project Overview

Our product is a UAV VTOL (Vertical Take-Off and Landing) non-autonomous quadcopter drone that can be controlled remotely via a controller. It consists of four rotors with independent motors, an X-shaped frame, buzzer, a battery, FPV camera system, gyroscope and accelerometer. If time permits, the video data from the camera system will be used for more advanced image processing (ex. object detection). The gyroscope allows for precise positioning and control of flying direction.

The intended audience for this drone is anyone interested in aerospace or aviation, enthusiasts looking for a fun new hobby, or researchers who might need an aerial device for experiments. Professional filmmakers, photographers, and search and rescue teams would be highly interested in models of the drone with a camera and advanced image processing.

### 1.2 Purpose and Scope of this Specification

The purpose of this specification is to allow people to have access to an aerial device that can be flown for personal enjoyment, exploration purposes or experimental projects. Combined with a camera, it can be used to capture images without physically being present, which can be useful for elderly people and people with disabilities. Law enforcement can use the drone to surveille or monitor dangerous areas and identify any safety hazards. People who want to explore new places without actually using air transportation can also use it! Adding a GPS onto the drone will be helpful for search and rescue teams looking for a lost item or person.

We are the designers of the product and Mr.Roller is our manager. Our made-up client is a Canadian drone manufacturer that wants us to design and build a prototype for a new quadcopter drone model. The end user will be the customers who are looking to purchase a drone.

Curriculum expectations and client requirements shall be met with this project. This project will begin in September, with research and design taking place in the first two months. Building, testing, and development of the actual product will take place from late October to January. The product will be finished by late January.

## 2. Product Description

### 2.1 Product Context

This drone relates to other products by having the possibility to integrate other components to increase its functionality such as a camera for video streaming. This product includes two main pieces, the drone and the controller. They are independent and self-contained from the environment. The drone can interface with Raspberry Pi Pico, a FPV camera, an Xbox controller and Arduino,

### 2.2 User Characteristics

General Characteristics for all customer profiles:

- Thorough knowledge of safety procedures for operating a drone
- Have experience and practice flying quadcopter drones in acro mode
- Have spare parts available to replace certain components (ex. propellers) in case of crash or damage
- Know how to operate a Xbox controller
- Know how to charge a Lipo battery with correct safety precautions

Student:

- Ages 14+ can fly alone or else adult supervision is highly recommended

Other possible customers:

- Pilots
- Aerospace engineer
- Law enforcement

### 2.3 Assumptions/Risks

1. Know how to charge a Lipo battery with proper safety precautions
2. Safety equipment and potential drone hazards/safety training (safety glasses, gloves)
3. Know how to fly a quadcopter drone
4. The drone shall flown from a safe distance from other people

Equipment availability:

1. Raspberry Pi Pico (RP2040)
2. 4 ESCs with integrated BECs,
  a. They must have a burst rating that is higher than the maximum amp draw of the motors
3. 4 brushless motors
4. MPU-6050 & NRF24L01
5. 4S Lipo Battery
6. Computer to view camera video
7. Compatible Arduino* for the RC controller
8. FPV camera with VTX transmitter and antenna
9. UVC receiver compatible with a computer
10. Active buzzer with built-in battery
11. F450 frame

### 2.4 Constraints

1. Streaming video requires a minimum computer RAM of 4GB - 8GB
2. Users need an XBox controller to control the drone and a computer to receive the streaming video

### 2.5 Dependencies

1. Software that allows a Raspberry Pi get data from the RF transceiver
2. Arduino library for getting data from the XBox controller.

## 3.Requirements

### 3.1 Functional and Hardware Requirements

#### 3.1.1 General Functional Objectives

Req# | Requirement | Comments | Date Rvwd | Customer Reviewed / Approved
HRS-3.1.1.1 | The drone shall be VTOL (vertical take-off & landing), meaning that the drone can take off and land vertically without a runway | | 10/09/24 | Mr. Roller
HRS-3.1.1.2 | The drone shall fly in rate mode/acro mode, meaning that the pilot needs to manually change the rate of orientation of all three axes | Unless there is a change in orientation made by the pilot, the drone shall continue flying in at the rate of orientation previously set by the pilot. The drone shall not go back to being parallel to the ground if the pilot lets go of the controller sticks (i.e. not horizontal or angle mode). | 10/09/24 | Mr. Roller
HRS-3.1.1.3 | The drone shall be able to pitch and roll forward and backwards as well as yaw left and right according to the mechanical input device | The orientation will be controlled through an Xbox controller | 10/09/24 | Mr. Roller
HRS-3.1.1.4 | The drone shall have a self-powered active buzzer for locating the drone in case it crashes or gets lost | The buzzer can be set off via a button on the RC transmitter/controller if the battery is connected. | 10/09/24 | Mr. Roller
HRS-3.1.1.5 | The drone shall have FPV camera system, where the video can be seen real-time on a computer | | 10/09/24 | Mr/Roller
HRS-3.1.1.6 | (Optional: Each propellor arm shall be lined with an LED strip as decoration and for easy identification of the drone in case it crashes) | | 10/09/24 | Mr. Roller
HRS-3.1.1.7 | (Optional: The drone shall have an ultrasonic sensor to detect any near obstacles to avoid collisions) | | 10/09/24 | Mr. Roller

#### 3.1.2 Propellers

Req# | Requirement | Comments | Date Rvwd | Customer Reviewed / Approved
HRS-3.1.2.1 | The drone shall have 4 wings/propellers | | 10/09/24 | Mr. Roller
HRS-3.1.2.2 | Each wing shall operate via a brushless motor which is connected to a 2-blade propeller | | 10/09/24 | Mr. Roller
HRS-3.1.2.3 | Each motor shall be controller via an ESC with an integrated BEC | The ESCs supply three-phase power to each motor | 10/09/24 | Mr. Roller

3.1.3 Mechanical Chassis/Drone Frame

Req# | Requirement | Comments | Date Rvwd | Customer Reviewed / Approved
HRS-3.1.3.1 | The drone shall use a F540 frame | Wheelbase: 450mm Max take-off weight: approx. 1.8kg All internal interfaces between components will be attached to the drone frame The drone frame comes with a PDB | 10/09/24 | Mr. Roller

#### 3.1.4 Flight Controller (FC)

Req# | Requirement | Comments | Date Rvwd | Customer Reviewed / Approved
HRS-3.1.4.1 | The FC shall be built via a Raspberry Pi Pico (RP2040) and coded using Micropython | | 10/09/24 | Mr. Roller
HRS-3.1.4.2 | The drone shall use a MPU-6050 as the Inertial Measurement Unit(IMU) to detect its movement. The FC will be connected to the IMU | The MPU-6050 includes a gyroscope and accelerometer. It is a widely used motion-tracking sensor with 6 degrees of freedom | 10/09/24 | Mr. Roller
HRS-3.1.4.3 | The FC shall calculate how much thrust should be applied to each motor to achieve the orientation on the three axes based on the pilot’s input | It shall adjust the thrust based on the PID calculation with the gyroscope and accelerometer values | 10/09/24 | Mr. Roller
HRS-3.1.4.4 | The FC shall communicate with the 4 ESCs to control the amount of thrust applied to each individual motor | The ESCs will act as the bridge between the motors and the FC. Each ESC will have an integrated BEC to step-down the battery’s voltage | 10/09/24 | Mr. Roller
HRS-3.1.4.5 | The FC shall receive the pilot’s input from the on- board RC receiver | The radio receiver receives signals via a RF Transceiver (NRF24L01) | 10/09/24 | Mr. Roller
HRS-3.1.4.6 | The FC shall be powered through one of the ESCs | Since the ESCs will step down the voltage from the battery to 5V, the Raspberry will use the ESC as a voltage regulator instead of an external step-down converter | 10/09/24 | Mr. Roller

(Optional/In case Raspberry Pi FC doesn’t work: Use a Speedybee F405 FC or an Arduino Micro)

#### 3.1.5 Camera

Req# | Requirement | Comments | Date Rvwd | Customer Reviewed / Approved
HRS-3.1.5.1 | The FPV camera shall be able to stream video to a computer via a VTX transmitter and antenna | The FPV camera we shall be purchasing comes integrated with the VTX transmitter and antenna | 10/09/24 | Mr. Roller
HRS-3.1.5.2 | (Optional: There shall be a button to enable and disable the stream of video) | | 10/09/24 | Mr. Roller
HRS-3.1.5.3 | (Optional: The video data shall be analyzed and be able to detect objects) | Image processing would be done through the computer | 10/09/24 | Mr. Roller

#### 3.2 User Interface Requirements

Req# | Requirement | Comments | Date Rvwd | Customer Reviewed / Approved
HRS-3.2.1 | Users shall control the orientation of the drone via a remote controller/radio controller that includes a RF transceiver module (NRF24L01), an XBox controller, and an Arduino board that connects the two parts together | It will communicate to a receiver via a 2.4GHz radio transmission. The receiver for the RF transceiver will be attached to the drone to receive commands | 10/09/24 | Mr. Roller
HRS-3.2.2 | The drone shall have an on and off switch, located on the drone frame Optional: It shall also have an emergency button to “kill” the drone if necessary | “kill” = stop the program from running | 10/09/24 | Mr. Roller
HRS-3.2.3 | The camera shall stream the video data to a computer for viewing | The computer will get video data through a UVC receiver | 10/09/24 | Mr. Roller
HRS-3.2.4 | The drone shall have a programming/debugging port for reprogramming the Raspberry Pi. | Via micro-USB B port | 10/09/24 | Mr. Roller
HRS-3.2.5 | Users shall be able to wirelessly control/program the Raspberry Pi via SSH from an external network. | | 10/09/24 | Mr. Roller

### 3.3 Hardware Interfaces

Any communication interfaces and necessary protocols that exist in your hardware system, both internal and external.

#### 3.3.1 Internal Interfaces (drone)

Req# | Requirement | Comments | Date Rvwd | Customer Reviewed / Approved
HRS-3.3.1.1 | The Raspberry Pi shall communicate with the ESCs using port GP 2, 28, 15, 16 through PWM | | 10/09/24 | Mr. Roller
HRS-3.3.1.2 | SSH network shall be used to wirelessly upload code onto the Raspberry Pi | | 10/09/24 | Mr. Roller
HRS-3.3.1.3 | The FC shall receive the pilot’s input from the on-board RF transceiver (NRF24L01) via GP17, GP14, GP6, GP7, and GP4 | | 10/09/24 | Mr. Roller
HRS-3.3.1.4 | The IMC(MPU-6050) shall receive and send signals via the GP13 (SCL) and GP 12 (SAD) using the I2C protocol | | 10/09/24 | Mr. Roller
HRS-3.3.1.5 | The buzzer shall receive signals via GP3 | | 10/09/24 | Mr.Roller

#### 3.3.2 External Interfaces (Controller, FPV monitor)

Req# | Requirement | Comments | Date Rvwd | Customer Reviewed / Approved
HRS-3.3.2.1 | The RF transceiver on the drone shall communicate with the RF transceiver on the controller through radio transmission. | Radio transmission shall be standard 2.4 GHz frequency RF transceiver module: On drone: NRF24L01 On controller: NRF24L01 + PA + LNA | 10/09/24 | Mr. Roller
HRS-3.3.2.2 | The VTX transmitter shall convert video signals from the camera to radio signals. The signals are then transmitted to the antenna. The antenna transmits the signals to the RC receiver, which is connected to the computer | Radio transmission shall use 5.8Ghz frequency The RC receiver connects to the antenna using RP-SMA female and to the computer using Type-C or micro-usb port | 10/09/24 | Mr. Roller
HRS-3.3.2.3 | The RF Transceiver(NRF20L04) on the controller shall receive signals from the Arduino via pin CE, CSN, SCK, MOSI, MOSO. | | 10/09/24 | Mr. Roller

## 4. Requirements Confirmation/Stakeholder sign-off

Meeting Date | Attendees (name and role) | Comments
10/09/24 | Jennifer and Annie, Mr. Roller, AeroVironment (Drone manufacturer) | Confirmed HRS-3.1.1.1 - HRS-3.3.2.3

### APPENDIX

The appendix should not be considered as part of the requirements.

#### Appendix A. Definitions, Acronyms, and Abbreviations

All terms, acronyms, and abbreviations used in this document.

ESC: Electronic Speed Controller

PID Controller: Proportional – Integral – Derivative controller

IMU: Inertial Measurement Unit.

- The IMU module used in this project is MPU-6050, which includes a gyroscope and accelerometer. It is a widely used motion-tracking sensor with 6 degrees of freedom.

FC: Flight Controller/Raspberry Pi Pico (RP)

Transceiver: A combination transmitter/receiver

Gyro: Gyroscope

#### Appendix B. References

https://datasheets.raspberrypi.com/pico/pico-datasheet.pdf

https://timhanewich.medium.com/taking-flight-with-the-raspberry-pi-pico-micropython-diy-quadcopter-drone-61ed4f7ee746

https://brownspace.org/how-to-build-a-drone/

https://oscarliang.com/lipo-battery-guide/

https://www.instructables.com/How-to-Build-a-Rc-Drone-and-the-Transmitter-Using-/

https://coffeebreakpoint.com/micropython/how-to-connect-a-nrf24l01-transceiver-to-your-raspberry-pi-pico/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

https://www.hackster.io/akarsh98/diy-radio-controller-for-drone-nrf24l01-fd7867

https://github.com/AndyRids/pico-nrf24

https://www.amazon.ca/HAWKS-WORK-Quadcopter-Original-version/dp/B09YQ4G4ZZ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

https://www.amazon.ca/VIFLY-Finder-Battery-Compatible-Standalone/dp/B07JB65HZC?th=1

https://www.amazon.ca/Wolfwhoop-Adjustable-Transmitter-Cloverleaf-Aircraft/dp/B06XB2ZRBP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

https://www.ebay.ca/itm/255299303750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

https://www.aliexpress.com/item/1005006426977793.html?src=google#nav-specification

https://dronenodes.com/how-to-build-a-drone/

http://quadcopterforum.com/threads/need-help-deciding-whether-to-use-a-pdb-or-a-4-in-one-esc.16210/

https://www.droneblog.com/fpv-drones-vs-regular-drones/

https://www.youtube.com/watch?v=CiFRNJUUdwM

https://www.youtube.com/watch?v=5BmaKVHan_c

https://brainright.com/drone/

Hardware Requirements Specification for Drone

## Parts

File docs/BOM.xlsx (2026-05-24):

Product name | Product Description | Amount | Unit Price | Shipping Fee | Total Price | Link
Raspberry Pi Pico |  | 1 |  |  |  | https://www.pishop.ca/product/raspberry-pi-pico-non-wireless/?src=raspberrypi
MPU6050 | Gikfun GY-521 MPU-6050 3 Axis Accelerometer Gyroscope Module | 1 |  |  |  | Gikfun GY-521 MPU-6050 3 Axis Accelerometer Gyroscope Module 6 DOF 6-axis Accelerometer Gyroscope Sensor Module for Arduino DIY(Pack of 3) EK1091x3C (https://www.amazon.ca/sspa/click)
ESCs | RC-Brushless 80A | 4 |  |  |  | https://www.amazon.com/RC-Brushless-Electric-Controller-bullet/dp/B071GRSFBD?th=1
Motors | Sunnysky 2212 980kv brushless motors | 4 |  |  |  | https://sunnyskyusa.com/products/sunnysky-a2212-motors-multirotor-version
F450 Frame | HAWK’S WORK F450 Drone Frame | 1 | $27.99 |  |  | https://www.amazon.ca/HAWKS-WORK-Quadcopter-Original-version/dp/B09YQ4G4ZZ
Propeller guard |  | 1 | $10.05 |  |  | https://www.aliexpress.com/item/1005008709400103.html?curPageLogUid=58NwBPFRkHeL
NRF2401 transceivers |  | 1 |  |  |  | https://www.amazon.ca/diymore-NRF24L01-Transceiver-Development-Compatible/dp/B0CGTWQ1BP
4S 3300mAh Lipo Battery |  | 1 |  |  |  | https://www.amazon.ca/3300mAh-Battery-Helicopter-Airplane-Quadcopter/dp/B06XKQJZ8D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
Battery Charger |  | 1 |  |  |  | https://www.amazon.ca/Hobby-Fans-Professional-Balance-Discharger/dp/B09XC91BWJ?sp_csd=d2lkZ2V0TmFtZT1zcF9hdGY
9450 Propellers | DJI Phantom 8Pcs/Set Self-Locking Quadcopter Blades - 4 x 9450 CW + 4 x 9450 CCW | 4 |  |  |  | https://www.aliexpress.com/item/32844447546.html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
ESP 32-CAM-MB |  | 1 |  |  |  | https://www.amazon.ca/dp/B0CGRK4PZ9/ref=twister_B0DG61WS8R?_encoding=UTF8&th=1
Arduino (Leonardo) |  | 1 |  |  |  | https://www.amazon.ca/Leonardo-Headers-Compatible-Revision-Atmega32u4/dp/B00R237VGO?s=electronics

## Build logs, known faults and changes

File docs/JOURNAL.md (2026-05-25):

# Journal

## 5.16

Completed:
- Created a folder for this project
- Organized existing files into their designated spots
Challenge:
- The pre created schematics might be in a different computer / lost -> find it next time

## 5.19

Research Parts
- Gathered datasheets of all the parts
- Started a BOM to record all required parts

Researched propellers - and found the price on aliexpress is half the prince on Amazon lmao

## 5.20

Completed:
- Migrated and continued working on the schematics
    - Couldn't find the old one :(
    - Created the symbol for MPU6050 and ESCs, and also checked the connection between the Raspberry Pi and NRF.
- Continue work on BOM

## 5.21

Completed:
- Researched how to integrate the camera
    - could use ESP32-CAM
    - Pre program it using local wife -> stream a network -> power using raspberry pi
- Verified the schematics parts
    - decide to power the Cam using ESC 5V

Challenge: still not sure how the CAM works

## 5.22

Completed:
- Continue working on schematics
    - wired the majority of the parts
- Confirmed the camera would work

Challenge:
- have to figure out how to power the nrf24l01 - need some kind of power adapter to convert 5v to 3.3v

## 5.23

Completed:
- Filled the schematics parts with a background color - looks more professional
- Continue worked on BOM
    - Organized the materials and included a link to product
    - Considered the option to buy drone legs only instead of the full frame
- Started the zine page
    - design principle: show the change from v1 to v2

## 5.24

Completed
- Modified Schematics based on actual connections
    - Power MPU6050 (VCC) using 3.3v from raspberry pi pico (U1-36) instead of 5v from ESC (U6-2)
    - Do SCL and SDA from MPU6050 need a pull up from 3.3V raspberry pi pico? - both 4.7k resistors
    - used 5v to power nrf24l01
- Update footprints

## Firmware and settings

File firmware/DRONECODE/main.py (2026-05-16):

from machine import Pin, PWM
from time import sleep, ticks_ms, ticks_add, ticks_diff
from MPU_data import MPU6050DATA
from RFClass import RFClass
import os

# From 1/12/2025 - 1/24/2025
# - detects angle for emergency stop
# - with PID
# - Controller + add in RF message to include controller adjustments
#     [0] take off/landing, [1:3] pitch, [3:5] roll, [5:7] yaw, [7:9] throttle adjustment (+-0.01 by each click)
# Analize Data: DOWNLOAD THE FILE BEFORE UNPLUGGING THE BATTERY

# Future: Better tune PID and improve the angle calculation algorithm

# LED indication:
# - end with on: toggled checkRotation()
# - end with off: finished the entire loop

# Initial Objects
led = Pin(25, Pin.OUT)

mpu = MPU6050DATA(id=0, sda=12, scl=13)
rf = RFClass()

# Initialize ESCs
esc_1 = PWM(Pin(15)) # Top Left - weaker one - changed to pin 15, originally pin 14 
esc_2 = PWM(Pin(2)) # bottom left - ccw
esc_3 = PWM(Pin(28)) # Bottom right
esc_4 = PWM(Pin(16)) # Top right - ccw

esc_1.freq(50)
esc_2.freq(50)
esc_3.freq(50)
esc_4.freq(50)

# deletes current file
os.remove('/angleData.txt')
os.remove('/throttleData.txt')
# Open file to log data
angleFile = open('angleData.txt', 'w') # mode(r, a, w, x, t,b)
throttleFile = open('throttleData.txt', 'w')
        
# Initialize variables
period_ms = 20
max_throttle = int ((2/ period_ms) * 65535)
min_throttle = int ((1/ period_ms) * 65535)
init_throttle = 1.1
goal_throttle = int ((init_throttle/ period_ms) * 65535)
# offset for each motor
t1_ofs_throttle = int ((0.035/ period_ms) * 65535)
t2_ofs_throttle = int ((0.0/ period_ms) * 65535)
t3_ofs_throttle = int ((0.01/ period_ms) * 65535)
t4_ofs_throttle = int ((0.01/ period_ms) * 65535)
steps = 100  # Define the number of steps
duty_step = (goal_throttle - min_throttle) // steps

maxThrottleDuration = 120 * 1000 # in ms
hasTilted = False

takeOff = False #phase
landing = False
changeDutyCycle = False
duty_cycle = min_throttle # starts with min throttle
endHoverTime = 0 # assigns value after takeoff

# PID Controller values
pid_pitch_kp:float = 7.5#5.5,8.5
pid_pitch_ki:float = 0#.4
pid_pitch_kd:float = 0.8#0.8
pid_roll_kp:float = 8.5#1.0.,8.5
pid_roll_ki:float = 0#.4
pid_roll_kd:float = 0.85#0.8
pid_yaw_kp:float = 1#1.0
pid_yaw_ki:float = 0#.1
pid_yaw_kd:float = 0#.5
i_limit = 30 # max value i can reach

roll_last_integral:float = 0.0 # default to 0. Accumulates throughout
roll_last_error:float = 0.0 # error value. currently = angle for hovering. Future = goal-current angle
pitch_last_integral:float = 0.0
pitch_last_error:float = 0.0
yaw_last_integral:float = 0.0
yaw_last_error:float = 0.0

transition_throttle = int ((1.1/ period_ms) * 65535) # when it switch from motor set duty_cycle to adding pid values

# Define functions
def stopAll() -> None: # stop all motors
    esc_1.duty_u16(min_throttle)
    esc_2.duty_u16(min_throttle)
    esc_3.duty_u16(min_throttle)
    esc_4.duty_u16(min_throttle)
    
def constrainThrottle(t1, t2, t3, t4): # constrain throttle to between min to max throttle
    t1 = max(min(t1, max_throttle), min_throttle)
    t2 = max(min(t2, max_throttle), min_throttle)
    t3 = max(min(t3, max_throttle), min_throttle)
    t4 = max(min(t4, max_throttle), min_throttle)
    return t1,t2,t3,t4

try:

    # Turn on the LED
    led.value(1)

    # set all motors to min throttle for calibration
    esc_1.duty_u16(min_throttle)
    esc_2.duty_u16(min_throttle)
    esc_3.duty_u16(min_throttle)
    esc_4.duty_u16(min_throttle)
    
    # Wait for the motors to calibrate
    sleep (10)
    
    mpu.calibrateGyro()
    
    previous_time = ticks_ms()
    
    count = 0 # to count how many message received. For debugging
    
    # wait for take off signal
    while not takeOff: 
        if rf.existsMessage():
            if rf.updateMessage() != None: # Received a message in the correct format
                takeOff = rf.getState()
    
    while True:
        
        current_time = ticks_ms()
        
        # Checks for any rf message
        if rf.existsMessage():
            # newest_throttle: similar to 1.1. newest_goal: after calculation like 4320
            if rf.updateMessage() != None:
                if rf.getState() == 0: # land
                    takeOff = False
                    landing = True
                else:
                    duty_cycle = int (((init_throttle + rf.getThrottle() / 100)/ period_ms) * 65535) # Calculate new duty_cycle from 1.00 to 2.00
        
        angle = [(rf.getPitch(), rf.getRoll(), rf.getYaw())[i] - mpu.getAngle()[i] for i in range(3)] # get difference between controller's goal and current angle
                
        count += 1
        #loop time
        loop_time = ticks_diff(current_time, previous_time) / 1000.0
        loop_time = max(loop_time, 1e-6)
        
        # pitch PID calc
        pitch_p:float = angle[0] * pid_pitch_kp
        pitch_i:float = pitch_last_integral + (angle[0] * pid_pitch_ki * loop_time)
        pitch_i = max(min(pitch_i, i_limit), -i_limit) # constrain within I-term limits
        pitch_d:float = pid_pitch_kd * (angle[0] - pitch_last_error) / loop_time
        pid_pitch = pitch_p + pitch_i + pitch_d #in original tutorial is p+i+d
        
        # roll PID calc
        roll_p:float = angle[1] * pid_roll_kp
        roll_i:float = roll_last_integral + (angle[1] * pid_roll_ki * loop_time)
        roll_i = max(min(roll_i, i_limit), -i_limit) # constrain within I-term limits
        roll_d:float = pid_roll_kd * (angle[1] - roll_last_error) / loop_time
        pid_roll:float = roll_p + roll_i + roll_d

        # Yaw PID Calculation
        yaw_p = angle[2] * pid_yaw_kp
        yaw_i = yaw_last_integral + angle[2] * pid_yaw_ki * loop_time
        yaw_i = max(min(yaw_i, i_limit), -i_limit)  # Constrain the integral term
        yaw_d = pid_yaw_kd * (angle[2] - yaw_last_error) / loop_time
        pid_yaw = yaw_p + yaw_i + yaw_d
        
        previous_time = current_time
        
        # calculate the throttle for each motor - t1 matches with esc_1
        t1 = t1_ofs_throttle + int(duty_cycle - pid_pitch - pid_roll + pid_yaw)  # Motor 1
        t2 = t2_ofs_throttle + int(duty_cycle + pid_pitch - pid_roll - pid_yaw)  # Motor 2
        t3 = t3_ofs_throttle + int(duty_cycle + pid_pitch + pid_roll + pid_yaw)  # Motor 3
        t4 = t4_ofs_throttle + int(duty_cycle - pid_pitch + pid_roll - pid_yaw)  # Motor 4

        t1,t2,t3,t4 = constrainThrottle(t1,t2,t3,t4)
        
       
        if takeOff: #while taking off

            # set motors to duty cyle - first time at min throttle
            if duty_cycle > transition_throttle: # to prevent having a throttle < min throttle and having a large angle error that might affect take off
                esc_1.duty_u16(t1)
                esc_2.duty_u16(t2)
                esc_3.duty_u16(t3)
                esc_4.duty_u16(t4)
            else: 
                esc_1.duty_u16(duty_cycle + t1_ofs_throttle)
                esc_2.duty_u16(duty_cycle + t2_ofs_throttle)
                esc_3.duty_u16(duty_cycle + t3_ofs_throttle)
                esc_4.duty_u16(duty_cycle + t4_ofs_throttle)
            
            if(duty_cycle >= goal_throttle): # if reached goal throttle
                takeOff = False # Change state 
                endHoverTime = ticks_add(current_time, maxThrottleDuration) #find endtime
            else:
                duty_cycle += duty_step # if it has not reach goal throttle, keep increasing speed
                        
        elif landing: # Add a condition for the reduction of throttle such that the drone can reducethrottle without immediately going to null and landing
            
            # set motors to duty cyle - first time at goal throttle
            if duty_cycle > transition_throttle:
                esc_1.duty_u16(t1)
                esc_2.duty_u16(t2)
                esc_3.duty_u16(t3)
                esc_4.duty_u16(t4)
            else: 
                esc_1.duty_u16(duty_cycle + t1_ofs_throttle)
                esc_2.duty_u16(duty_cycle + t2_ofs_throttle)
                esc_3.duty_u16(duty_cycle + t3_ofs_throttle)
                esc_4.duty_u16(duty_cycle + t4_ofs_throttle)
                
            if duty_cycle <= min_throttle: ## if passed min throttle
                landing = False
                break # Break out of loop if landed
            else:
                duty_cycle -= duty_step # decrease duty cycle
                 
        else:
            #stay at same duty_cycle + PID adjustments
            esc_1.duty_u16(t1)
            esc_2.duty_u16(t2)
            esc_3.duty_u16(t3)
            esc_4.duty_u16(t4)
            
            # Set a time limit for hovering
            if(ticks_diff(endHoverTime, current_time) <= 0): # check how long it hovered
                  landing = True # change to landing if hovered for enough time
        
        # Save state values for next loop
        roll_last_error = angle[1]
        pitch_last_error = angle[0]
        yaw_last_error = angle[2]
        roll_last_integral = roll_i
        pitch_last_integral = pitch_i
        yaw_last_integral = yaw_i
        
        mpu.updateAngle()
        
        # For debgugging
#         print(count, [t1,t2,t3,t4], cmd_duty_step, duty_cycle)
#         print(f'on: {rf.getState()}, pitch: {rf.getPitch()}, roll: {rf.getRoll()}, yaw: {rf.getYaw()}, throttle: {rf.getThrottle()}')
#         print(takeOff, changeDutyCycle)
        if count % 100 == 0: # print every 100 loops
            print(angle, [t1, t2, t3, t4])
            
        # Write data to file
        angleFile.write(f"{angle[0]}, {angle[1]}, {angle[2]}, {current_time}\n")
        throttleFile.write(f"{t1}, {t2}, {t3}, {t4}\n")
        
        # Check if the drone has tilted
        if(mpu.checkRotationAngle()): 
            stopAll() 
            hasTilted = True
            led.toggle()
            break
        
        sleep(0.005)
        
    stopAll()      
    led.toggle()
    print('Finished')
    angleFile.close()
    throttleFile.close()
    
except KeyboardInterrupt:
    print("Keyboard interrupt")
    stopAll()
    esc_1.deinit()
    esc_1.deinit()
    esc_1.deinit()
    esc_1.deinit()
